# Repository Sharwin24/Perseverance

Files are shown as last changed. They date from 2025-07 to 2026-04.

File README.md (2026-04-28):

# Perseverance
Mobile Robot resembling NASA's Mars Perseverance Rover. Everything from scratch and open-source including mechanical design, electronics, and software. The end goal of this project is to gain experience with mobile robotics concepts including SLAM, state estimation, and dynamic environment navigation.

## Work In Progress


This project is currently in progress and I'm currently focusing on the drive-base with the following tasks:

- Building a Kalman Filter focusing on the kinematic model of a 6-wheel Mars Rover
- ~~Creating a PPO RL training pipeline for a simplified mobile robot and goal pose navigation~~
- Working on firmware for motor board (RoverFirmware)
- Designing a carrier PCB to connect the MCU with motors, sensors, and power.

---

<div style="display: flex; justify-content: center; align-items: flex-start; gap: 12px;">
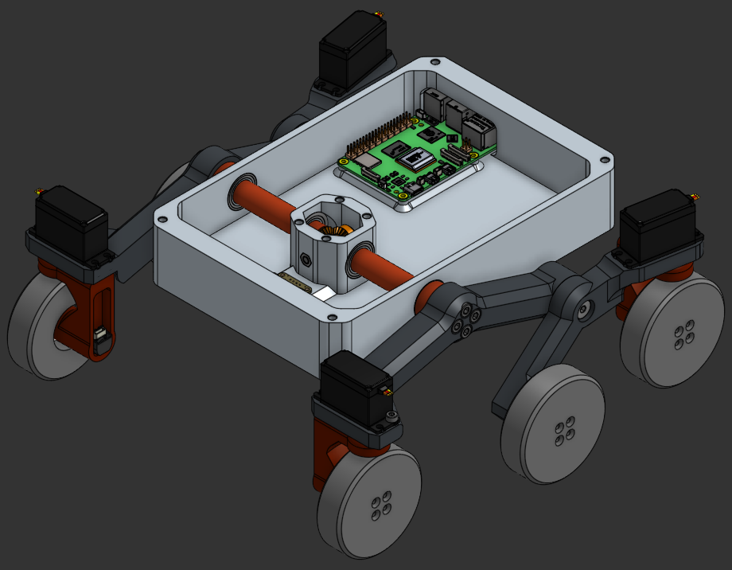
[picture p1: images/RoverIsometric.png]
Isometric CAD View
  
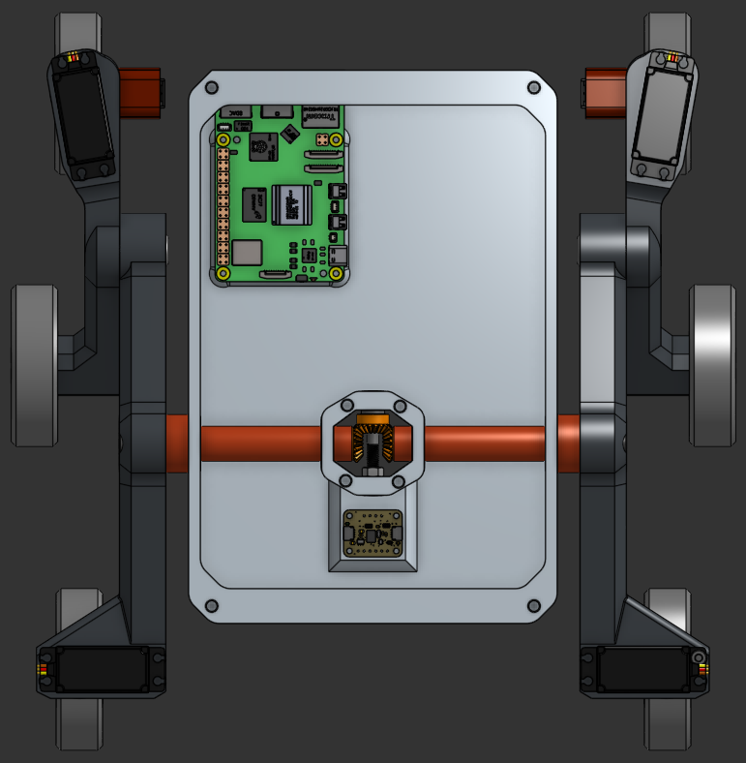
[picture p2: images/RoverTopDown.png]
Top Down CAD View
  
</div>

<div style="display: flex; justify-content: center; align-items: center; width: 80%;">
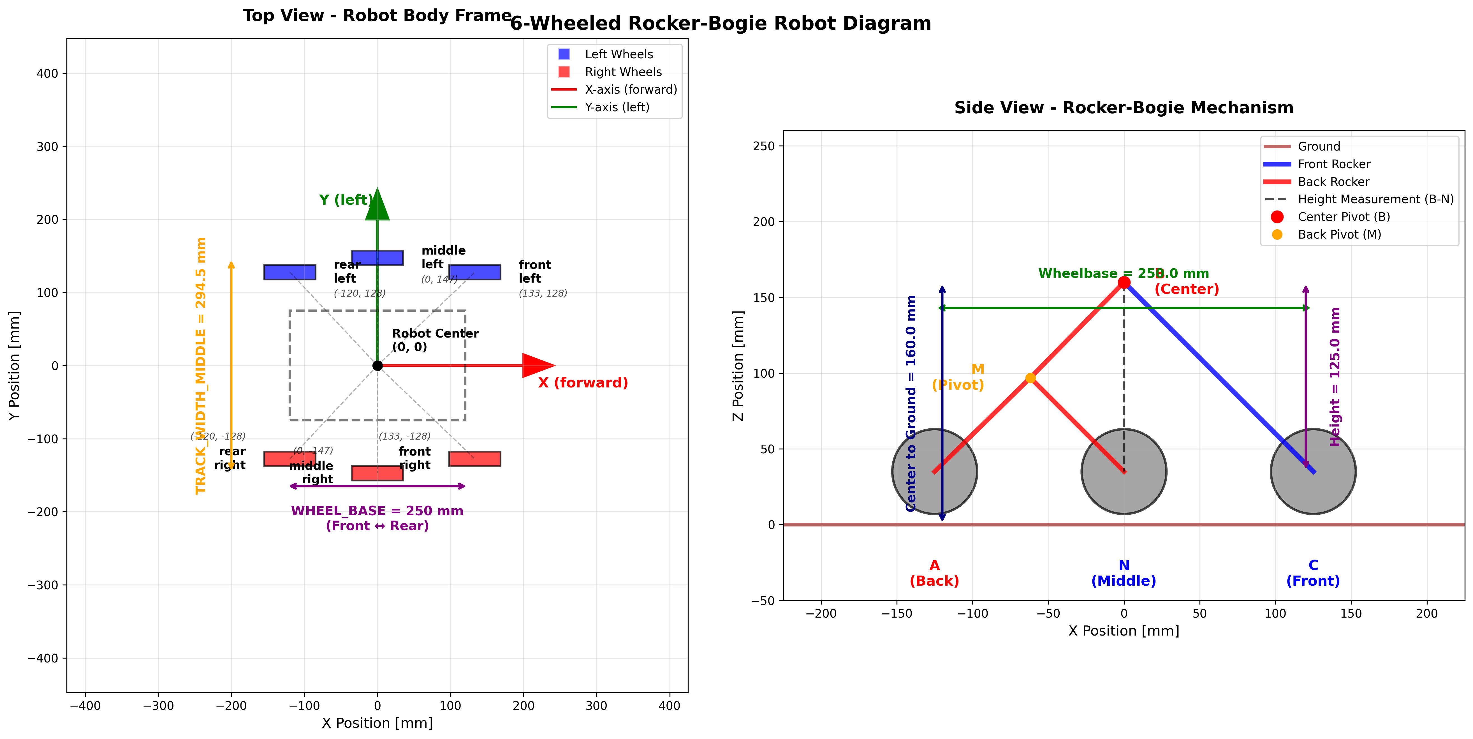
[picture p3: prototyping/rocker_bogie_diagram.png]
  
</div>

*This plot was generated with `draw_rocker_bogie.py`*

*A lot of the math expressions aren't rendering correctly and can best be visualized by viewing the markdown render locally in an IDE (VS Code). It's a work in progress to create SVG images for each equation and display them once they are finalized...*

<div style="display: flex; justify-content: center; align-items: center; width: 50%;">
  RoverTeleop
</div>

*Simulated Teleoperation in pygame with ackerman steering, try it out by running `rover_teleop.py` in `prototyping/`!*

---

# References
- [Path Following using Visual Odometry for a Mars Rover
in High-Slip Environments](https://www-robotics.jpl.nasa.gov/media/documents/helmick04_aeroconf.pdf)
- [Feature-Based Scanning LiDAR-Inertial Odometry Using Factor Graph Optimization](https://ieeexplore.ieee.org/abstract/document/10100875/authors#authors)
- [Autonomous robotics is driving Perseverance rover’s progress on Mars](https://www.science.org/doi/10.1126/scirobotics.adi3099)
- [A Friction-Based Kinematic Model for
Skid-Steer Wheeled Mobile Robots](https://amrl.cs.utexas.edu/papers/icra2019_skid_steer_kinematics.pdf)
- [Kalman Filter Overview](https://www.kalmanfilter.net/default.aspx)
- [Ghost IV — Sensor Fusion: Encoders + IMU](https://medium.com/hackernoon/ghost-iv-sensor-fusion-encoders-imu-c099dd40a7b)
- [Design of Rocker-Bogie Mechanism](https://ijisrt.com/wp-content/uploads/2017/05/Design-of-Rocker-Bogie-Mechanism-1.pdf)
- [The Challenges of Designing the Rocker-Bogie Suspension
for the Mars Exploration Rover](https://esmats.eu/amspapers/pastpapers/pdfs/2004/harrington.pdf)
- [Design and Fabrication of six wheels Rocker Bogie Mechanisms](https://sist.sathyabama.ac.in/sist_naac/aqar_2022_2023/documents/1.3.4/mechatronics_batch%20no.21.pdf)
- [Understanding and Making Rocker-Bogie System](https://docs.sunfounder.com/projects/galaxy-rvr/en/latest/lesson2_rocker_bogie.html
)

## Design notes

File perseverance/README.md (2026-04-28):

# Perseverance (ROS2 Package)
Package for navigation and control of an autonomous Mars rover using ROS2. Modeled after NASA's Perseverance rover.

# Extended Kalman Filter for Rover State Estimation
Approximating the robot as a diff-drive robot makes it easier to compute the state transition matrix and derive the system dynamics/kinematics. Kinematic models for mecanum wheeled drive and rocker bogie suspension system are more complex, but better represent the robot's motion, and I've implemented motion models for all 3.

*Note: Each motion model still needs to be tested rigorously*

<div style="display: flex; justify-content: space-between; align-items: flex-start; gap: 8px;">
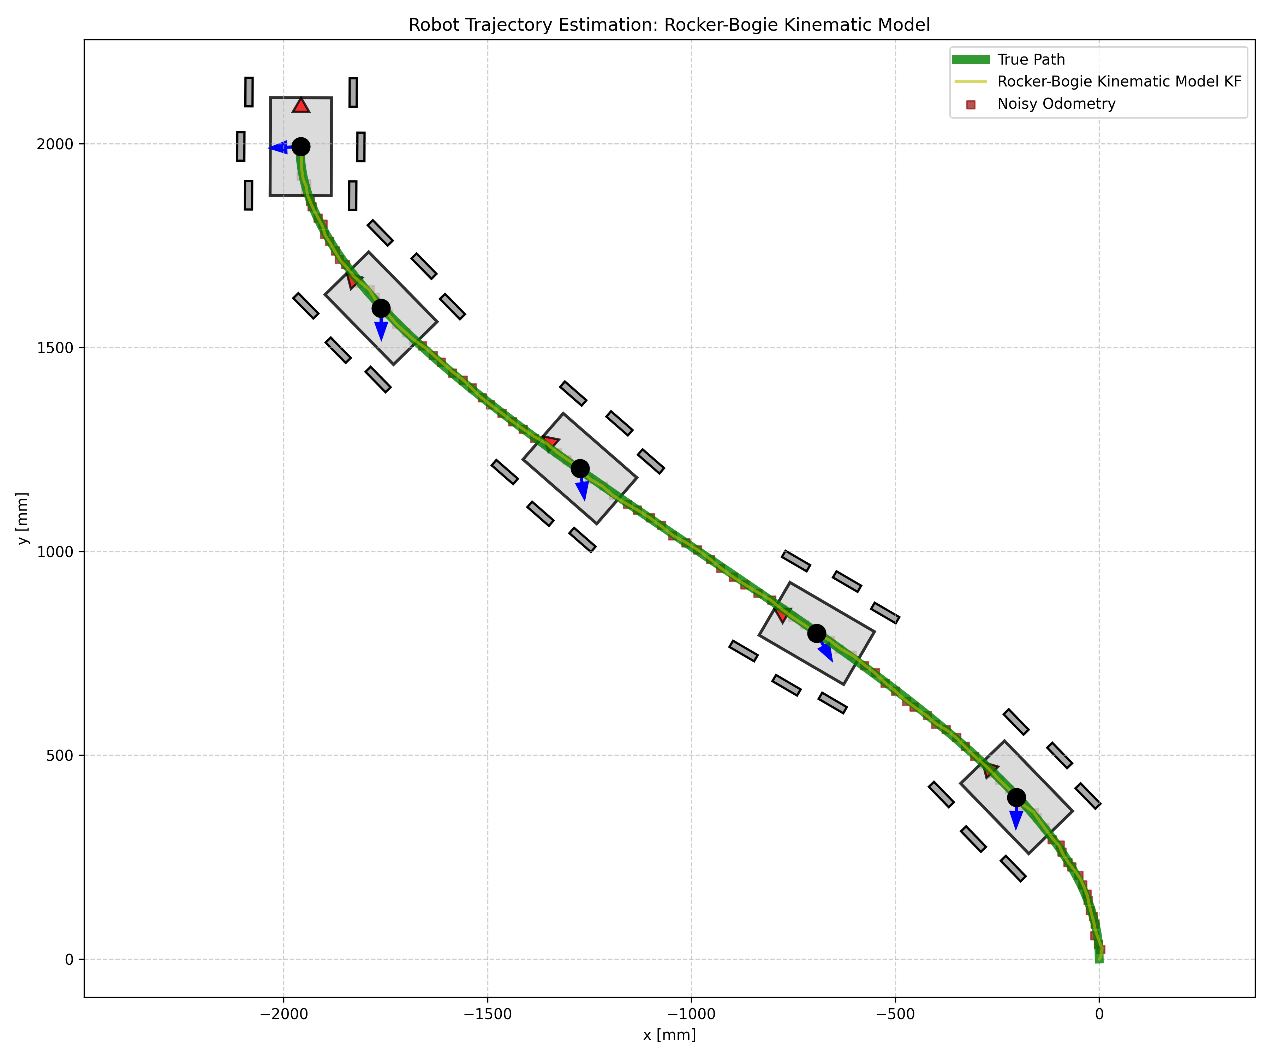
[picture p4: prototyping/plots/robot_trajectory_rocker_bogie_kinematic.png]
Robot Trajectory Comparison
  
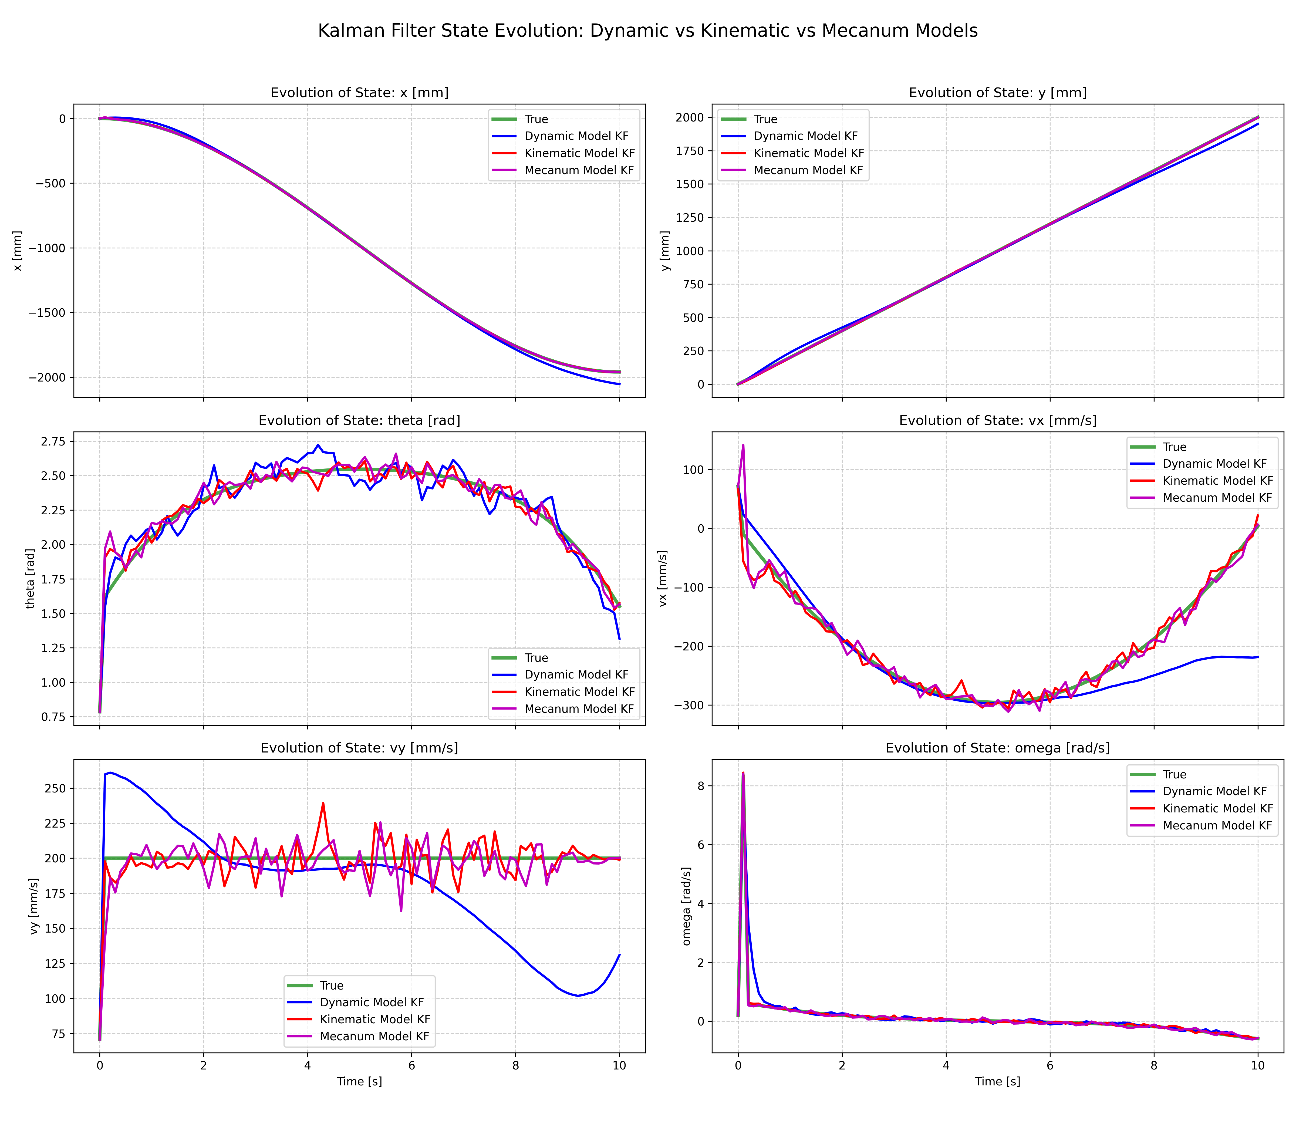
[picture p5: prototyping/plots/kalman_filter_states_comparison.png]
Kalman Filter States Comparison
  
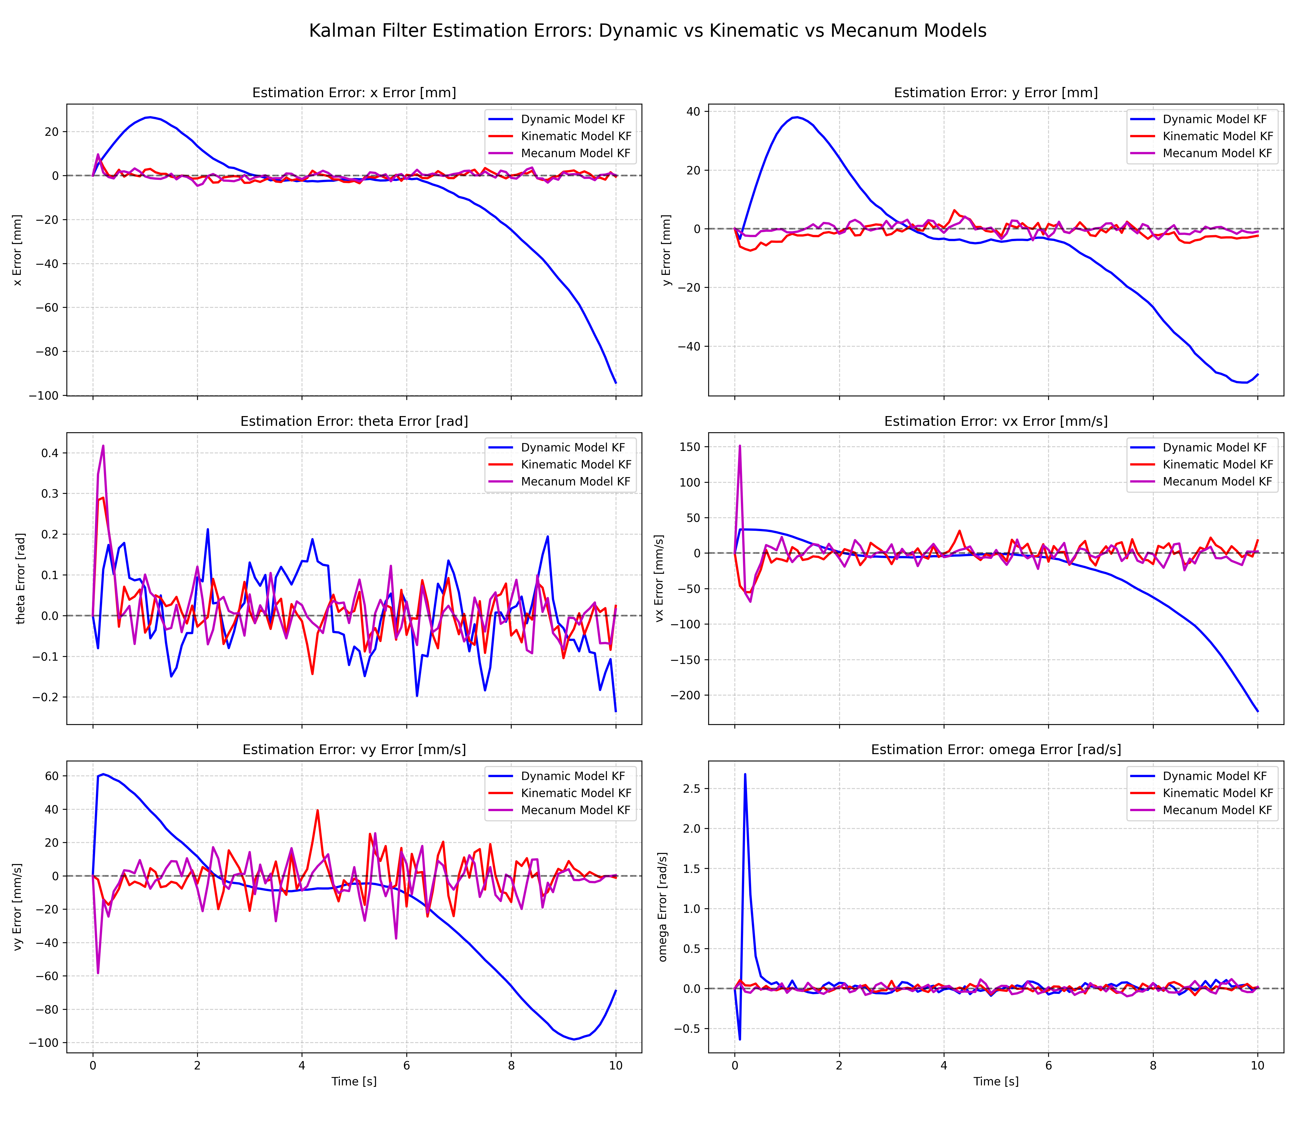
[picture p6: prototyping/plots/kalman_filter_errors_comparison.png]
Kalman Filter Errors Comparison
  
</div>

## Prediction Models

### Diff-drive Kinematic Model
The control input for the diff-drive robot is very simply both wheel velocities:

$$U_{\text{diff}} = \left[v_{left}, v_{right}\right]$$

The function that describes the state's evolution is the **process model:** $f\left(X_{prev}, U, \Delta t\right) \to X_{next}$ which correlates a previous state to the next state with some timestep $\Delta t$.

<!-- $$\begin{bmatrix}x \\ y \\ \theta \\ v_{x} \\ v_{y} \\ \omega \end{bmatrix} = \begin{bmatrix}x_{prev} + V \cos\theta_{prev} \Delta t \\ y_{prev} + V\sin\theta _{prev}\Delta t \\ \theta_{prev} + \omega \Delta t \\ V a_x \Delta t \\ V a_y \Delta t \\ \omega\end{bmatrix}$$ -->

<div style="display: flex; justify-content: center; align-items: center; width: 100%; background: black; padding: 10px; border-radius: 8px;">
  Process Model Equation
</div>

The state transition matrix $F$ (also known as the Jacobian of the process model) describes how a new state relates to the old state as a matrix of partial derivatives.

<!-- $$F = \begin{bmatrix} 1 & 0 & -V\sin(\theta)\Delta t & 0 & 0 & 0 \\ 0 & 1 & V\cos(\theta)\Delta t & 0 & 0 & 0 \\ 0 & 0 & 1 & 0 & 0 & 0 \\ 0 & 0 & -V\sin(\theta_{new}) & 0 & 0 & 0 \\ 0 & 0 & V\cos(\theta_{new}) & 0 & 0 & 0 \\ 0 & 0 & 0 & 0 & 0 & 0 \end{bmatrix}$$ -->

<div style="display: flex; justify-content: center; align-items: center; width: 100%; background: black; padding: 10px; border-radius: 8px;">
  F_diff_drive_kinematic Matrix
</div>

### Rocker-Bogie Suspension Kinematic Model
The rocker-bogie suspension has 6 powered wheels, 4 of which are able to rotate independently for ackerman-style steering. The control vector includes all wheel velocities and the 4 (outer) wheel steering angles:

$$U_{\text{rocker-bogie}} = \left[v_1, v_2, v_3, v_4, v_5, v_6, \theta_1, \theta_2, \theta_3, \theta_4\right]$$

Each wheel $i$ at position $(x_i,y_i)$ (in the body frame) with steering angle $\delta_i$ and drive speed $v_i$ provides two constraints on body-frame velocities $(v_{bx}, v_{by}, \omega_b)$:

$$\begin{aligned}
v_{bx} - \omega_b y_i &= v_i \cos\delta_i \\
v_{by} + \omega_b x_i &= v_i \sin\delta_i
\end{aligned}$$

Stacking all 6 wheels yields a linear system $A\,\mathbf{b} = \mathbf{m}$ with $A \in \mathbb{R}^{12\times 3}$, unknown $\mathbf{b} = [v_{bx}, v_{by}, \omega_b]^T$, and measurement vector $\mathbf{m}$ composed of $v_i\cos\delta_i, v_i\sin\delta_i$ pairs. The least-squares solution:

$$\begin{bmatrix} v_{bx} \\ v_{by} \\ \omega_b \end{bmatrix} = (A^{T}A)^{-1}A^{T} \mathbf{m} = A^{\dagger}\,\mathbf{m}$$

Body velocities are transformed to global frame and integrated:

$$\begin{aligned}
\dot{x} &= v_{bx}\cos\theta - v_{by}\sin\theta\\
\dot{y} &= v_{bx}\sin\theta + v_{by}\cos\theta\\
\dot{\theta} &= \omega_b
\end{aligned}$$

Discrete process model with state $X = [x, y, \theta, v_x, v_y, \omega]^T$ (using global-frame velocities $v_x, v_y$):

$$\begin{bmatrix} x_{k+1} \\ y_{k+1} \\ \theta_{k+1} \\ v_{x,k+1} \\ v_{y,k+1} \\ \omega_{k+1} \end{bmatrix} = \begin{bmatrix}
 x_k + v_{x,k}\Delta t \\
 y_k + v_{y,k}\Delta t \\
 \theta_k + \omega_k \Delta t \\
 v_{x}^{(b)\to g}(U_k) \\
 v_{y}^{(b)\to g}(U_k) \\
 \omega_b(U_k)
\end{bmatrix}$$

Because $v_x, v_y, \omega$ are fully determined by wheel inputs each step, their derivatives w.r.t prior velocities are zero in the Jacobian (similar sparsity to mecanum). Non-linear dependence enters only through the heading rotation applied to $(v_{bx}, v_{by})$.

<!-- $$
F = \frac{\delta f(X,U)}{\delta X} =\begin{bmatrix}\frac{\delta x_{new}}{\delta x} & \frac{\delta x_{new}}{\delta y} & \frac{\delta x_{new}}{\delta \theta} & \frac{\delta x_{new}}{\delta v_x} & \frac{\delta x_{new}}{\delta v_y}\\ \frac{\delta y_{new}}{\delta x} & \frac{\delta y_{new}}{\delta y} & \frac{\delta y_{new}}{\delta \theta} & \frac{\delta y_{new}}{\delta v_x} & \frac{\delta y_{new}}{\delta v_y}\\ \frac{\delta \theta_{new}}{\delta x} & \frac{\delta \theta_{new}}{\delta y} & \frac{\delta \theta_{new}}{\delta \theta} & \frac{\delta \theta_{new}}{\delta v_x} & \frac{\delta \theta_{new}}{\delta v_y}\\ \frac{\delta v_{x_{new}}}{\delta x} & \frac{\delta v_{x_{new}}}{\delta y} & \frac{\delta v_{x_{new}}}{\delta \theta} & \frac{v_{x_{new}}}{\delta v_x} & \frac{v_{y_{new}}}{\delta v_y} \\ \frac{\delta v_{y_{new}}}{\delta x} & \frac{\delta v_{y_{new}}}{\delta y} & \frac{\delta v_{y_{new}}}{\delta \theta} & \frac{v_{y_{new}}}{\delta v_x} & \frac{v_{y_{new}}}{\delta v_y}\end{bmatrix} = \begin{bmatrix} 1 & 0 & -V\sin(\theta)\Delta t & 0 & 0 & 0 \\ 0 & 1 & V\cos(\theta)\Delta t & 0 & 0 & 0 \\ 0 & 0 & 1 & 0 & 0 & 0 \\ 0 & 0 & -V\sin(\theta_{new}) & 0 & 0 & 0 \\ 0 & 0 & V\cos(\theta_{new}) & 0 & 0 & 0 \\ 0 & 0 & 0 & 0 & 0 & 0 \end{bmatrix}
$$ -->

<div style="display: flex; justify-content: center; align-items: center; width: 100%; background: black; padding: 10px; border-radius: 8px;">
  State Transition Matrix
</div>

Note that the new velocities and angular rate do not depend on the previous velocities or angular rate, making their corresponding derivatives zero. The new velocities, $(v_x, v_y)$ are determined by the control input $V$ and the *new* orientation $\theta_{new}$. This is a *non-linear* process model because of the use of trigonometric functions on the state variable $\theta$.

### Mobile Robot Dynamic (Acceleration-Based) Model
This model treats measured linear accelerations (e.g., IMU) as control inputs producing a constant-acceleration (CA) motion assumption over each small interval $\Delta t$.

State (extended to include velocities & yaw rate):
$$X = [x, y, \theta, v_x, v_y, \omega]^T$$

Control Vector (global-frame linear accelerations):
$$U_{\text{imu}} = [a_x, a_y]^T$$

Continuous dynamics (assuming measured $\omega$ is incorporated separately via a gyro measurement update):
$$\begin{aligned}
\dot{x} &= v_x & \dot{v}_x &= a_x \\
\dot{y} &= v_y & \dot{v}_y &= a_y \\
\dot{\theta} &= \omega & \dot{\omega} &= 0
\end{aligned}$$

Discretized (first-order) process model:
$$\begin{bmatrix} x_{k+1} \\ y_{k+1} \\ \theta_{k+1} \\ v_{x,k+1} \\ v_{y,k+1} \\ \omega_{k+1} \end{bmatrix} = \begin{bmatrix}
 x_k + v_{x,k}\Delta t + \tfrac{1}{2} a_{x,k}\Delta t^2 \\
 y_k + v_{y,k}\Delta t + \tfrac{1}{2} a_{y,k}\Delta t^2 \\
  heta_k + \omega_k \Delta t \\
 v_{x,k} + a_{x,k}\Delta t \\
 v_{y,k} + a_{y,k}\Delta t \\
 \omega_k
\end{bmatrix}$$

This can be written in linear form $X_{k+1} = F X_k + B U_k$ where:

$$F = \begin{bmatrix}
1 & 0 & 0 & \Delta t & 0 & 0 \\
0 & 1 & 0 & 0 & \Delta t & 0 \\
0 & 0 & 1 & 0 & 0 & \Delta t \\
0 & 0 & 0 & 1 & 0 & 0 \\
0 & 0 & 0 & 0 & 1 & 0 \\
0 & 0 & 0 & 0 & 0 & 1
\end{bmatrix}, \quad
B = \begin{bmatrix}
  \frac{1}{2}\Delta t^2 & 0 \\
0 & \frac{1}{2}\Delta t^2 \\
0 & 0 \\
\Delta t & 0 \\
0 & \Delta t \\
0 & 0
\end{bmatrix}$$

Yaw rate $\omega$ is modeled as constant between corrections (process noise captures drift). If desired, a third acceleration/torque input could be added to extend $B$ for angular acceleration.

## Robot State & Covariance
The goal of the prediction step in a Kalman filter is to use the prediction model to calculate how the robot's state evolves over a time step $\Delta t$. This model is based on control inputs, which are the commands we send to the robot. Any given state may have some error, and it's important to capture this uncertainty in our state representation with what we call a state covariance matrix, typically denoted as $P$. The state covariance matrix describes the uncertainty of each state variable and how they are correlated with each other, and is usually a diagonal matrix, unless there are state variables that are correlated with each other.

$$X = \left[x, y, \theta, v_x, v_y, \omega\right]$$

$$P = \begin{bmatrix}
\sigma_x^2 & 0 & 0 & 0 & 0 & 0 \\
0 & \sigma_y^2 & 0 & 0 & 0 & 0 \\
0 & 0 & \sigma_\theta^2 & 0 & 0 & 0 \\
0 & 0 & 0 & \sigma_{v_x}^2 & 0 & 0 \\
0 & 0 & 0 & 0 & \sigma_{v_y}^2 & 0 \\
0 & 0 & 0 & 0 & 0 & \sigma_\omega^2
\end{bmatrix}$$

### Tuning the Initial State Covariance $(P)$
The initial state covariance $P$ should be the variance of the initial state values. Typically the initial state is all zeros and the covariances can be small.

### Tuning the Process Noise Covariance $(Q)$
$Q$ represents how much confidence we have in our prediction model. Typically kinematic models are pretty robust, for diff-drive robots at least, but can accumulate some inaccuracy for skid-steering and mecanum wheeled drive bases. Smaller values trust the prediction model more, while larger values alot more trust to the sensor measurements that are used to correct the robot's state. This should be tuned last after tuning the initial covariance $P$, and the measurement covariances $R$ (discussed below).

### Updating Covariance Matrices
During each **prediction step**, we learn more about the system's dynamics and need to update our state-covariance matrix to reflect this new knowledge:

$$ P_{k+1} = F P_k F^T + Q $$

During the **update step**, we also need to update the state covariance matrix to reflect the new information gained from the sensor measurements. We do this with the kalman gain $K$, the innovation covariance $S$ and the measurement noise covariance $R$:

$$S = H P_{k} H^T + R$$

$$K = P_{k} H^T S^{-1}$$

$$P_{k+1} = (I - K H) P_{k}$$

## Sensor Fusion Updates
The correction step of the filter uses sensor measurements to refine the predicted state. For each sensor, we need a measurement model $H(X)$ that computes the expected measurement from a given state vector.

### IMU Sensor
The IMU measures the angular rate around the Z-axis $\omega$ as well as the linear acceleration $a_x, a_y$.

$$z_{imu} = \left[\omega, a_x, a_y\right]$$

The measurement model only needs to use the angular velocity

$$H_{imu}(X) = \left[0, 0, 0, 0, 0, 1\right]$$

### Odometry
Odometry uses wheel encoders coupled with knowledge about the robot's physical layout to obtain an estimate of the robot's pose:

$$z_{odom} = \left[x_{odom}, y_{odom}, \theta_{odom}\right]$$

The measurement model selects the pose elements from the state:

$$H_{odom}(X) = \left[1, 1, 1, 0, 0, 0\right]$$

### Tuning Measurement Noise Covariance $(R)$
Collect data with the robot sitting absolutely still for a specified length of time and calculate the variance of the data set for each sensor's respective values in the measurement model.

$$R \approx \sigma^2 = \frac{1}{N}\sum_i^N\left(x_i - \mu\right)^2$$

The datasheet for each sensor could prove to be useful if they've documented the sensor's noise density and/or standard deviation.

## State Estimation Pipeline
Now that we're equipped with jargon and the individual components of the EKF, we can outline the state estimation pipeline with some pseudocode:

```python
# 1. Initialize state and covariance
X = np.zeros((6, 1)) # [x, y, theta, v_x, v_y, omega]
P = np.eye(6) * 1e-3 # State Covariance Matrix
Q = np.eye(6) * 1e-3 # Process Noise Covariance Matrix
prev_estimate_time = 0 # Timestamp for the previous update

# Loop through prediction and update step
# This typically happens at a fixed time interval e.g. every 100ms or 10Hz
while True:
  # Calculate timestep between estimations
  current_time = now()
  dt = current_time - prev_estimate_time
  if (dt <= 0):
    continue;

  # 2. Prediction Step
  # 2.1 Predict the next state using the process model
  X_new = process_model(X, dt)

  # 2.2 Calculate the Jacobian F
  F = calculate_jacobian(X, dt)

  # 2.3. Update the state covariance
  P = F @ P @ F.T + Q

  # 3. Update Step
  for [z, H, R] in sensor_readings:
    # z is the measurement vector from the sensor
    # H is the measurement model matrix for the sensor
    # R is the measurement noise covariance for this sensor

    # 3.1 Calculate the innovation
    y = z - H @ X_new

    # 3.2 Calculate the innovation covariance [S]
    S = H @ P @ H.T + R

    # 3.3 Calculate the kalman gain [K]
    K = P @ H.T @ np.linalg.inv(S)

    # 3.4 Update the state estimate
    X = X_new + K @ y

    # 3.5 Update the state covariance
    P = (np.eye(6) - K @ H) @ P

  # Update estimate timestamp before next loop execution
  prev_estimate_timestamp = current_time
```

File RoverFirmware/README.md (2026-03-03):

# RoverFirmware
Firmware for the [**Adafruit Feather M4 Express**](https://www.adafruit.com/product/3857) (SAMD51, Cortex-M4F) on the rover, handling low-level motor control and SPI communication with the Raspberry Pi 5.

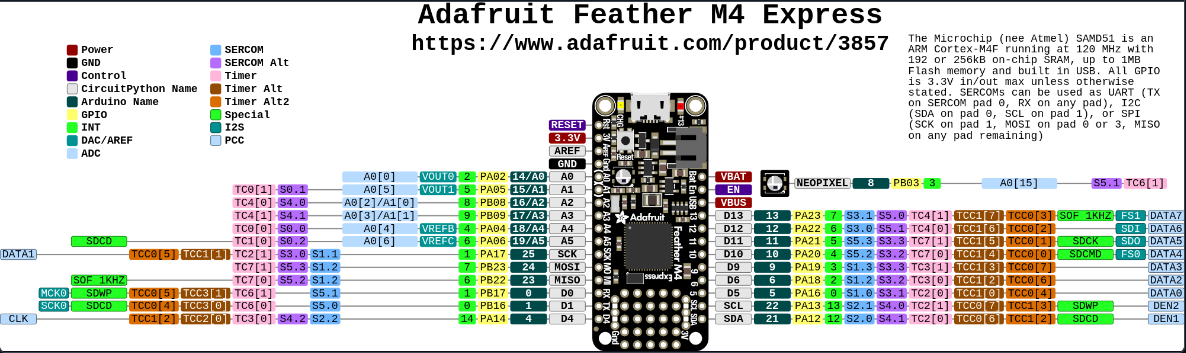
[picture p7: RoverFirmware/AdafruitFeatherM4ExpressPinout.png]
Adafruit Feather M4 Express Pinout


## Why the Feather M4 Express?

The M4 Express was chosen over alternatives (RP2040, Teensy 4.1) for the following reasons:

- **Hardware FPU:** The SAMD51 has a single-precision hardware FPU, making the PID loops across 6 motors at 100Hz fast and deterministic. The RP2040 has no hardware FPU, so all floating-point math runs in software emulation.
- **Interrupt-capable GPIOs:** Every digital pin supports external interrupts, covering all 12 pins needed for 6 quadrature encoders without workarounds.
- **Adafruit library compatibility:** First-class support for `Adafruit_MotorShield`, `Adafruit_BusIO`, and `Adafruit_MAX1704X`. The RP2040's community Arduino core has occasional compatibility quirks with these libraries.
- **PlatformIO support:** The M4 has native PlatformIO support. The RP2040 requires the community `maxgerhardt/platform-raspberrypi` platform and needed workarounds (e.g., `-DENCODER_DO_NOT_USE_INTERRUPTS`) that would defeat high-frequency encoder reading.

## Hardware Interfaces

1. Control 6 DC drive motors via 2× Adafruit Motor Shield FeatherWings (I2C)
2. Control 4 steering servos (PWM)
3. Read from 6 quadrature encoders (12 interrupt pins)
4. Communicate with Raspberry Pi 5 over SPI

## SPI Protocol

**RPi5 → M4:**
- 6 motor target speeds
- 4 servo steering angles

**M4 → RPi5:**
- 6 encoder counts (for wheel odometry)

## Concurrent Tasks

All tasks run cooperatively using `ArduinoThread`, checked in priority order in `loop()`:

| Priority | Task | Rate | Description |
|---|---|---|---|
| 1 | Encoder Task | 1 kHz | Reads 6 quadrature encoders and updates encoder counts |
| 2 | Motor Task | 100 Hz | PID velocity control for 6 DC motors, updates FeatherWing PWM |
| 3 | Steering Task | 100 Hz | Updates 4 steering servos based on RPi5 commands |
| 4 | Communication Task | 100 Hz | SPI — receives commands from RPi5, sends back encoder data |
| 5 | Battery Monitor Task | 0.5 Hz | Polls MAX17048 alerts and controls charging circuit |
| 6 | Heartbeat Task | 0.25 Hz | Pulses built-in LED to indicate scheduler is alive |

## Arduino / PlatformIO Dependencies

- [`Adafruit_MotorShield`](https://github.com/adafruit/Adafruit_Motor_Shield_V2_Library/blob/master/Adafruit_MotorShield.h)
- [`Adafruit_MS_PWMServoDriver`](https://github.com/adafruit/Adafruit_Motor_Shield_V2_Library/blob/master/utility/Adafruit_MS_PWMServoDriver.h)
- [`Adafruit_I2CDevice`](https://github.com/adafruit/Adafruit_BusIO/blob/master/Adafruit_I2CDevice.h)
- [`Adafruit_MAX1704X`](https://github.com/adafruit/Adafruit_MAX1704X) — battery fuel gauge
- [`ArduinoThread`](https://gitlab.com/airbornemint/arduino-protothreads) — cooperative multitasking

## Task Details

### Encoder Task (1 kHz)

Reads all 6 quadrature encoders using ISR-driven `Encoder` objects and stores the raw tick counts into the shared `encoderCounts[6]` array (`{FL, FR, ML, MR, RL, RR}`). Running at 1 kHz gives 1 ms resolution for the velocity estimation performed in the Motor Task.

### Motor Task (100 Hz)

Implements an independent PID velocity control loop for each of the 6 drive motors:

1. Computes `dt` in microseconds via `micros()` for precise, wrap-safe timing.
2. Derives current velocity for each motor as `(current_ticks - prev_ticks) / dt` in ticks/s.
3. Sets each PID controller's input to the measured velocity and setpoint to the commanded speed from `motorSpeedCommands[6]` (rad/s, populated by the Communication Task).
4. Maps the PID output (clamped to ±4095, 12-bit range) to `setSpeedFine()` on each `Adafruit_DCMotor`, with direction set by the sign of the output.

PID gains: `Kp = 2.0`, `Ki = 5.0`, `Kd = 1.0`. The two MotorShields sit at I2C addresses `0x60` (left side: FL, ML, RL) and `0x61` (right side: FR, MR, RR).

### Steering Task (100 Hz)

Reads the shared `servoAngleCommands[4]` array (`{FL, FR, RL, RR}` in radians) and writes positions to the 4 steering servos. Angles are converted from radians to degrees, then mapped from `[-90°, 90°]` to the `[0°, 180°]` servo range.

### Communication Task (100 Hz)

Handles the full-duplex SPI transaction with the Raspberry Pi 5:

- **TX (24 bytes):** 6 encoder counts packed as little-endian `uint32_t` values.
- **RX (40 bytes):** 6 motor speed `float`s (bytes 0–23) followed by 4 servo angle `float`s (bytes 24–39), all little-endian.

Values are unpacked via a `union { uint32_t u; float f; }` bitcast and written into `motorSpeedCommands` and `servoAngleCommands`. On a failed SPI transaction, previous command values are retained unchanged.

### Battery Monitor Task (0.5 Hz)

Polls the MAX17048 fuel gauge for active alerts and responds accordingly:

| Alert Flag | Action |
|---|---|
| `SOC_CHANGE` | Clear flag |
| `SOC_LOW` | Clear flag |
| `VOLTAGE_RESET` | Clear flag |
| `VOLTAGE_LOW` (< 3.25 V) | Assert `BATTERY_CHARGE_ENABLE_PIN` HIGH — enables charging circuit |
| `VOLTAGE_HIGH` (> 4.25 V) | Assert `BATTERY_CHARGE_ENABLE_PIN` LOW — disables charging circuit |
| `RESET_INDICATOR` | Clear flag |

Thresholds: low = 3.30 V, full = 4.20 V, hysteresis = 0.05 V (prevents rapid toggling at boundary voltages).

### Heartbeat Task (0.25 Hz)

Pulses the built-in LED for 100 ms every 4 seconds as a visual indicator that the cooperative scheduler is alive and not deadlocked.

---

## Motor Interface

`RoverMotorInterface` (RMI) wraps the two `Adafruit_MotorShield` instances and all 6 `Adafruit_DCMotor` objects. It:

1. Maintains 2 `Adafruit_MotorShield` instances (one per side of the rover)
2. Manages 6 `Adafruit_DCMotor` instances (3 per shield)
3. Exposes thread-safe setters for target velocities
4. Runs a PID control loop, reading encoder-derived velocity error and updating PWM output each Motor Task cycle

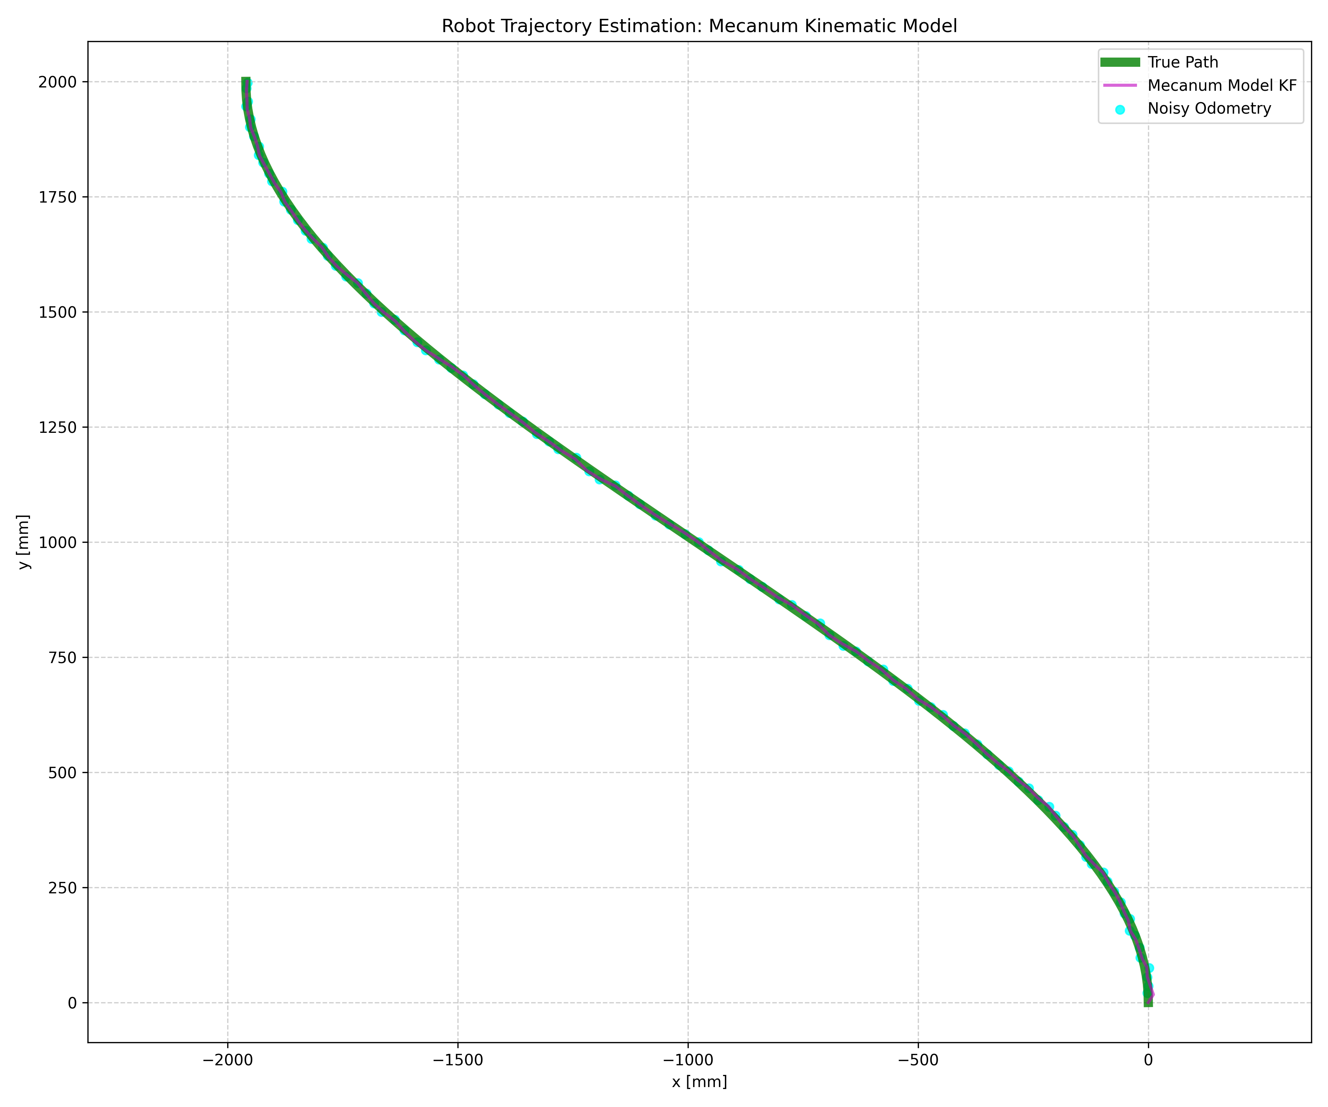
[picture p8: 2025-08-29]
prototyping/plots/robot_trajectory_mecanum_kinematic.png

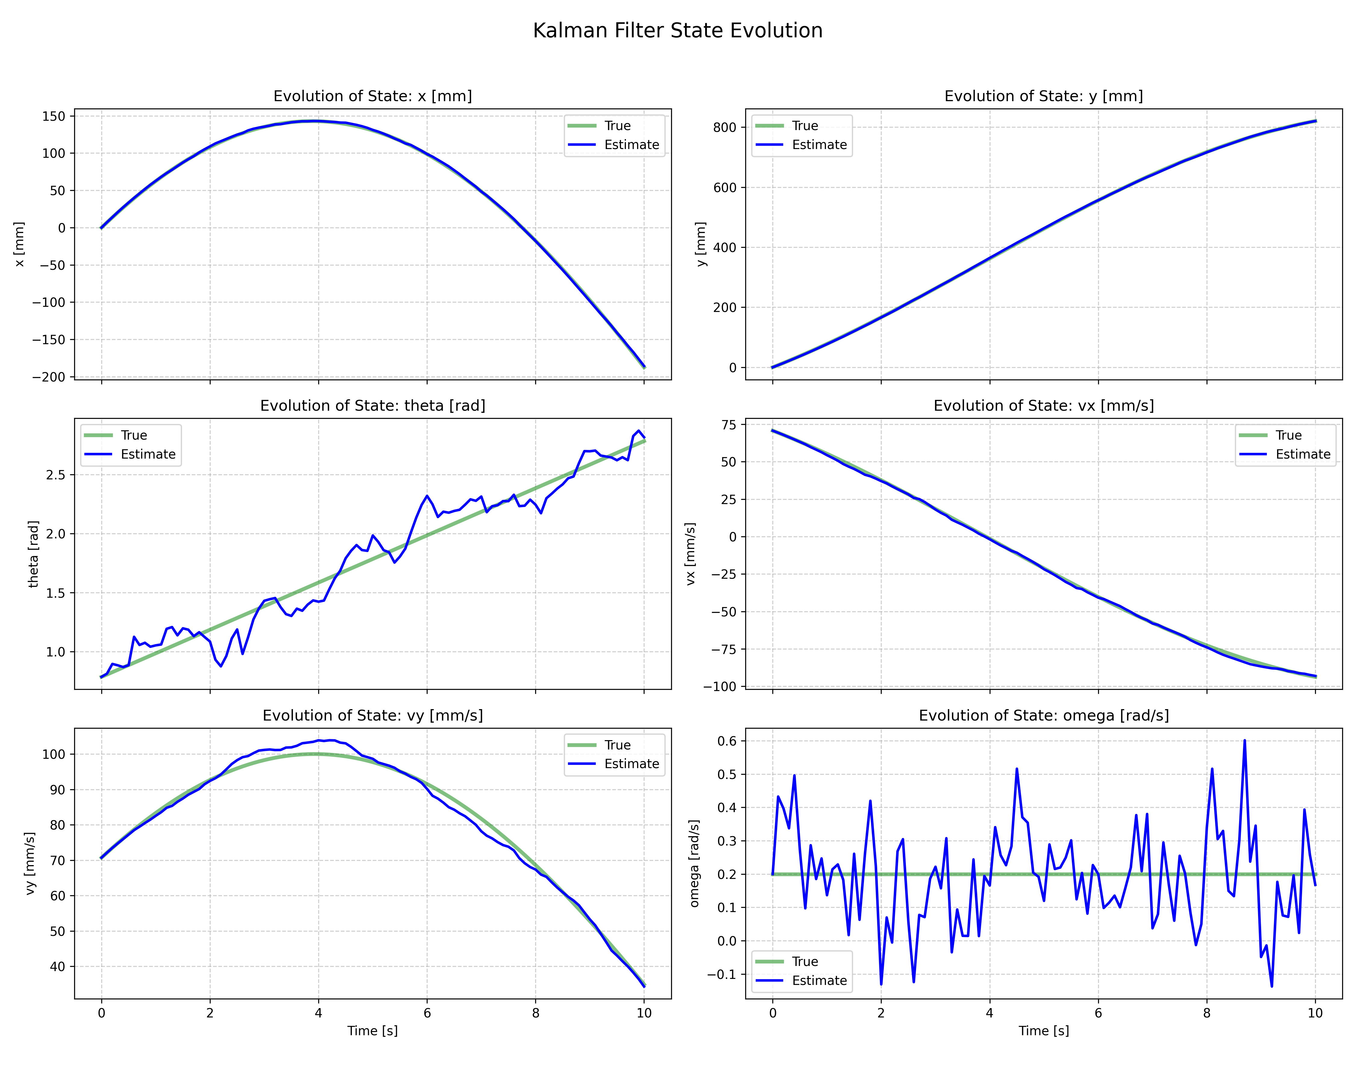
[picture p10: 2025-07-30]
prototyping/plots/gentle_curve/kalman_filter_states.png

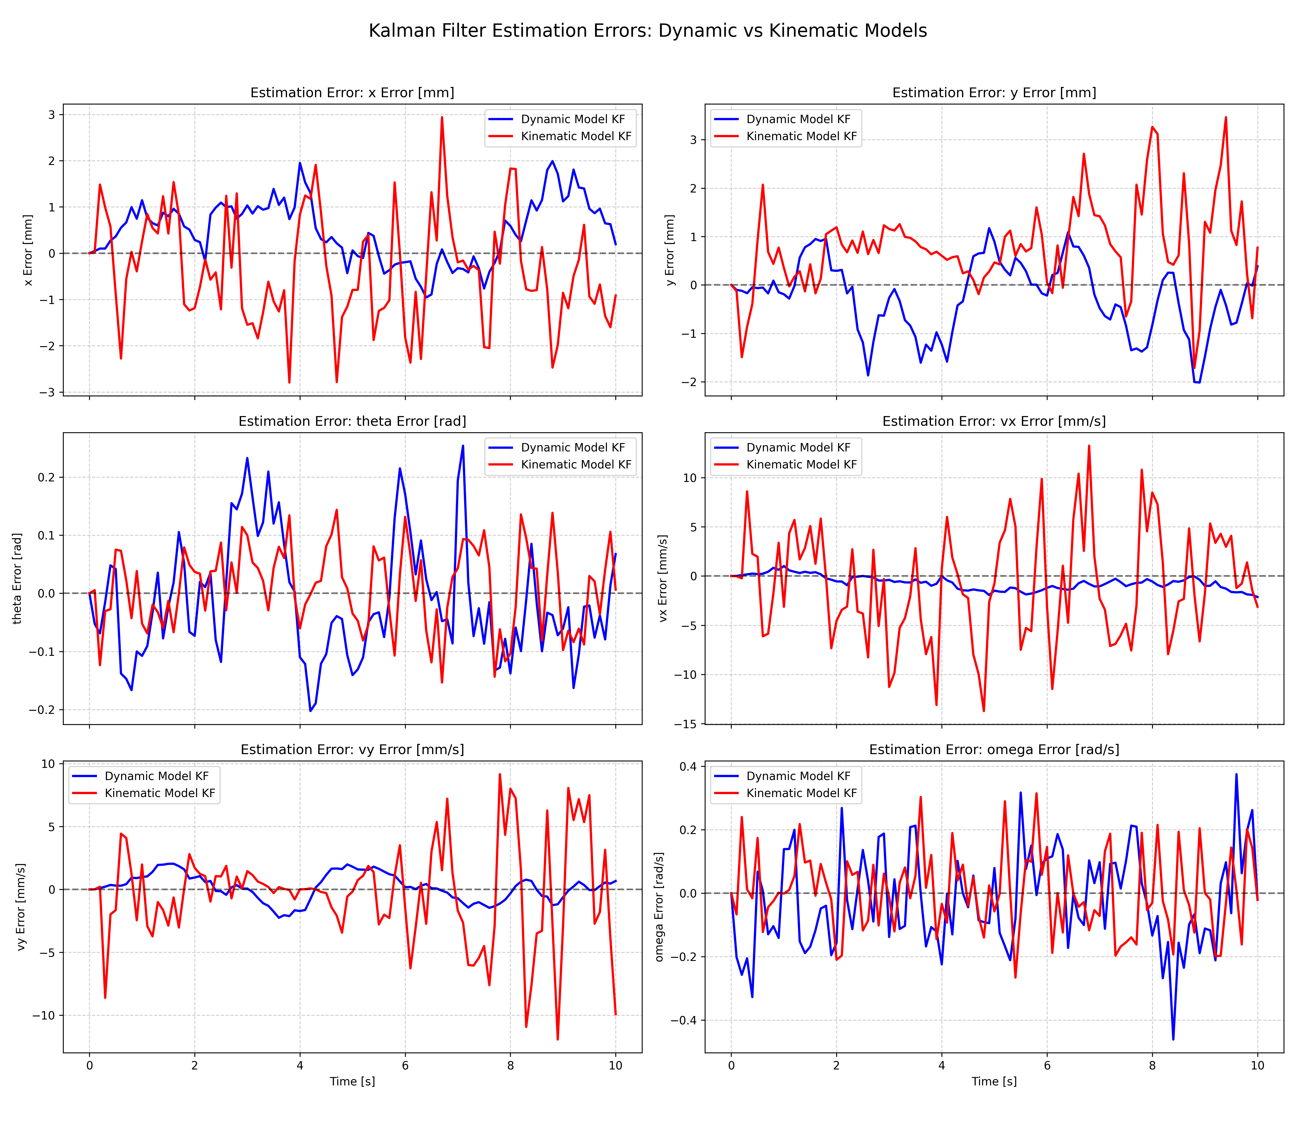
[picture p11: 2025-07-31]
prototyping/plots/gentle_curve/kalman_filter_errors_comparison.png

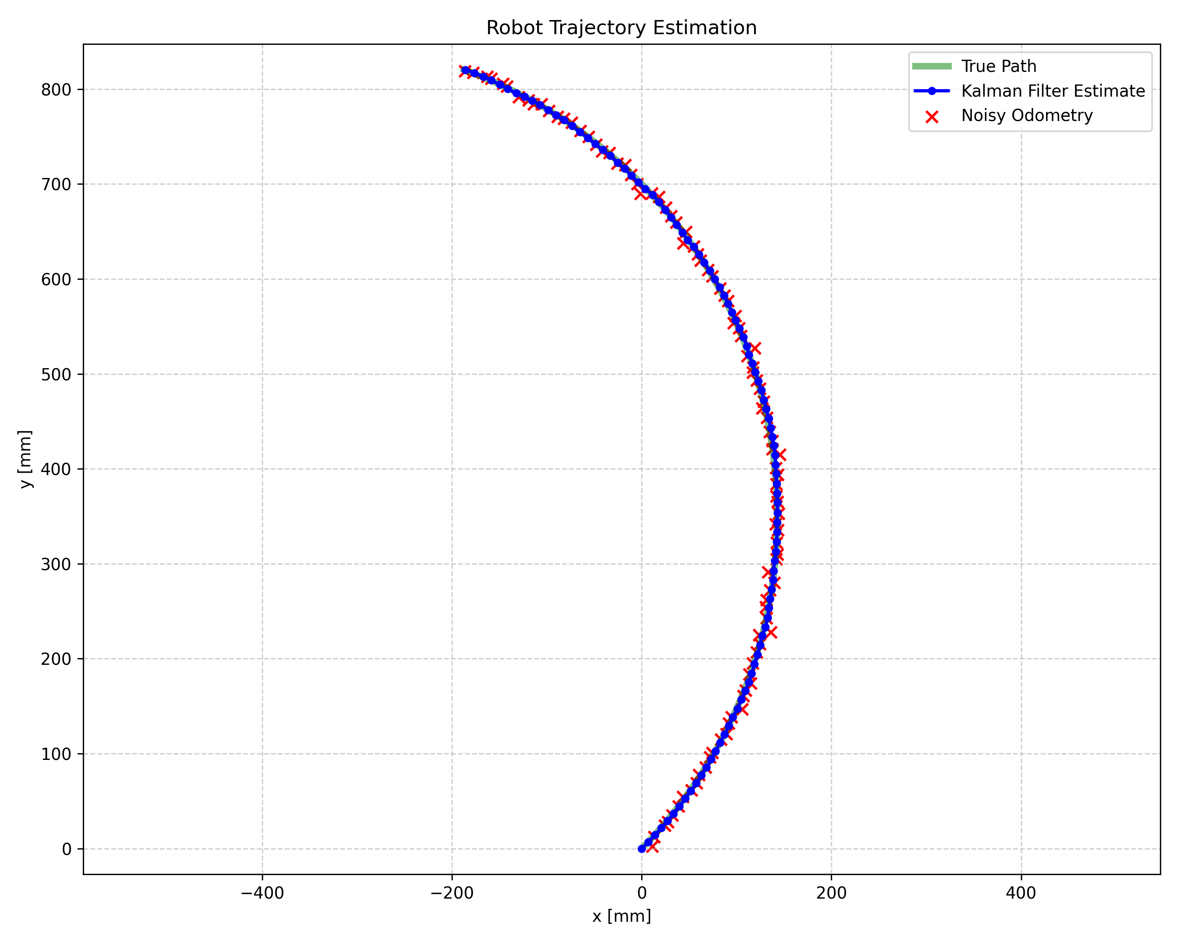
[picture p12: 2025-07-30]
prototyping/plots/gentle_curve/robot_trajectory.png

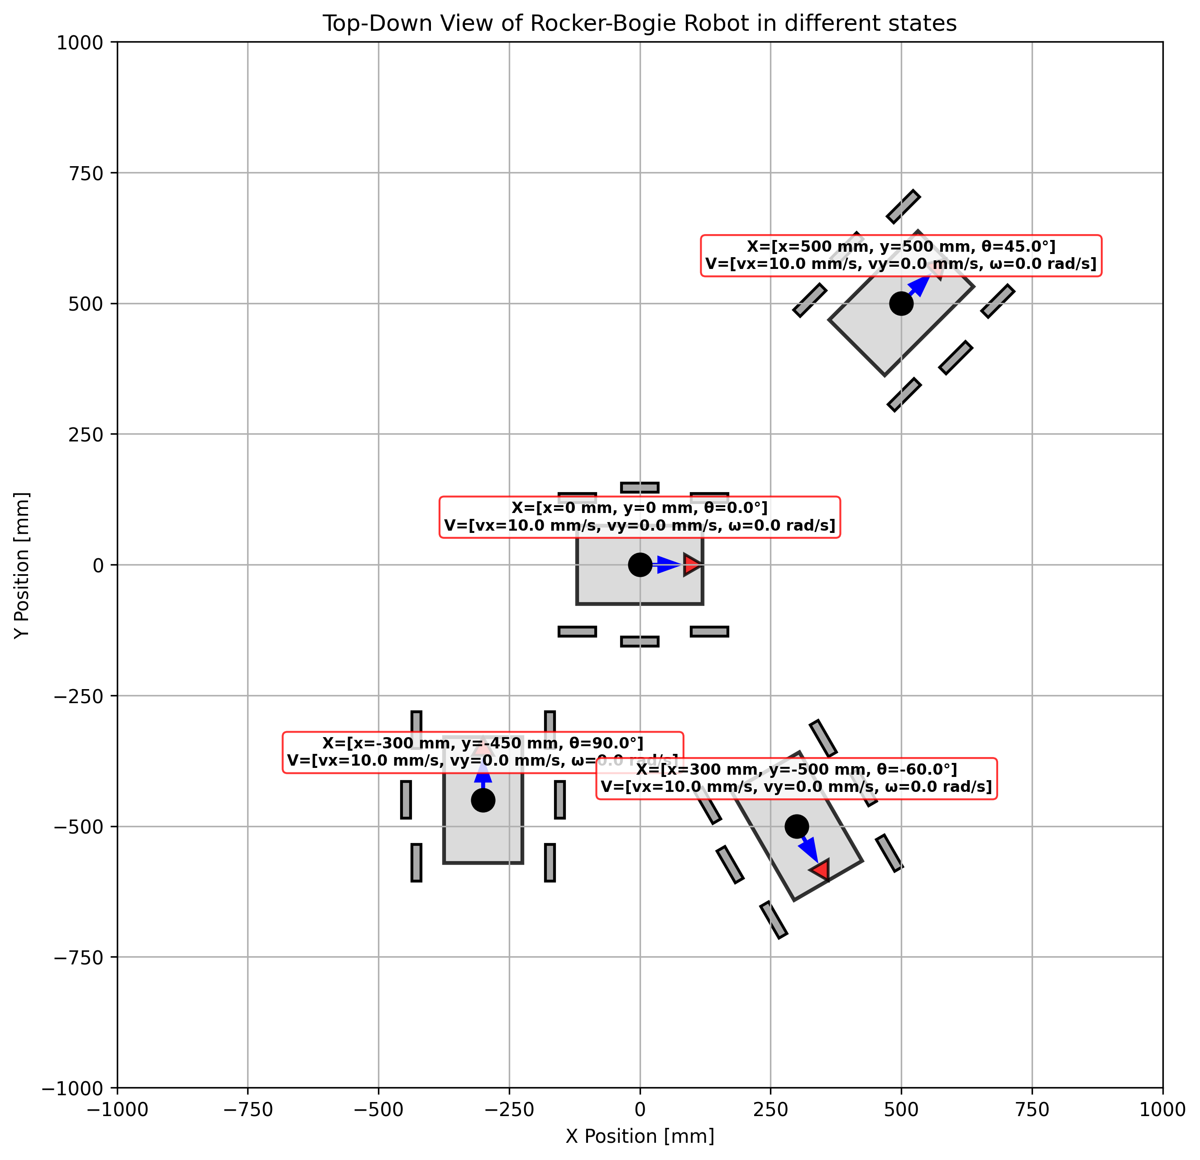
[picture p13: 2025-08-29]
prototyping/top_down_rover.png

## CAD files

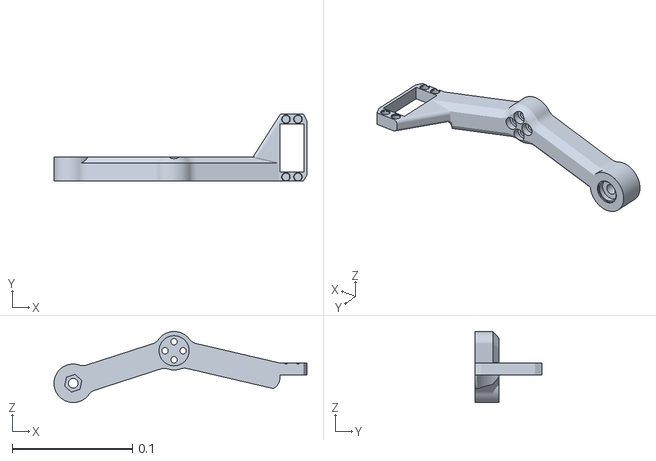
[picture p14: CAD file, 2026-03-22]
perseverance/urdf/leftrocker.stl
0.21 x 0.056 x 0.0591

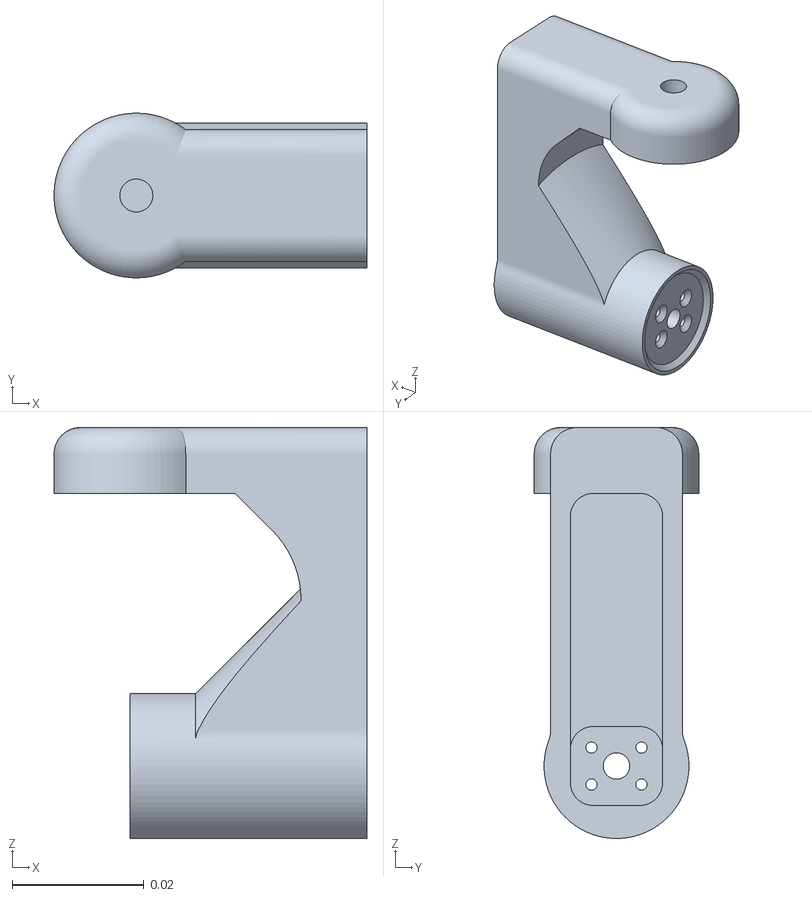
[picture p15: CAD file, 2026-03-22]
perseverance/urdf/rearsteeringarm.stl
0.0475 x 0.025 x 0.0624

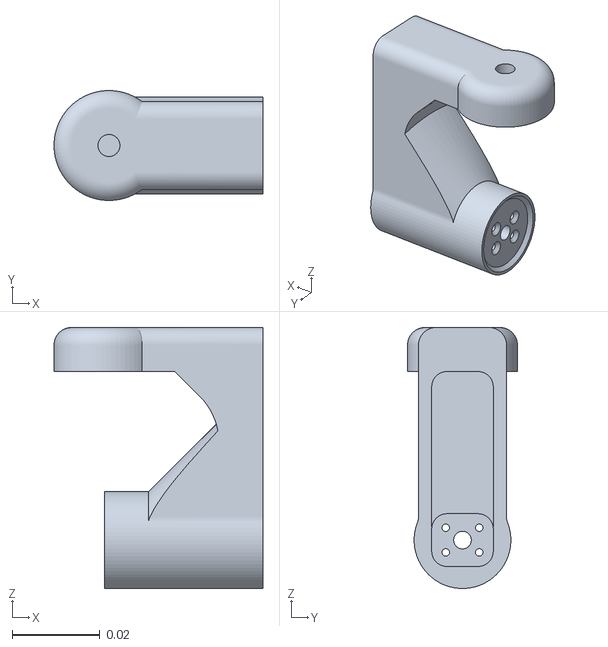
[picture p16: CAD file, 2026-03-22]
perseverance/urdf/frontsteeringarm.stl
0.0475 x 0.025 x 0.0593

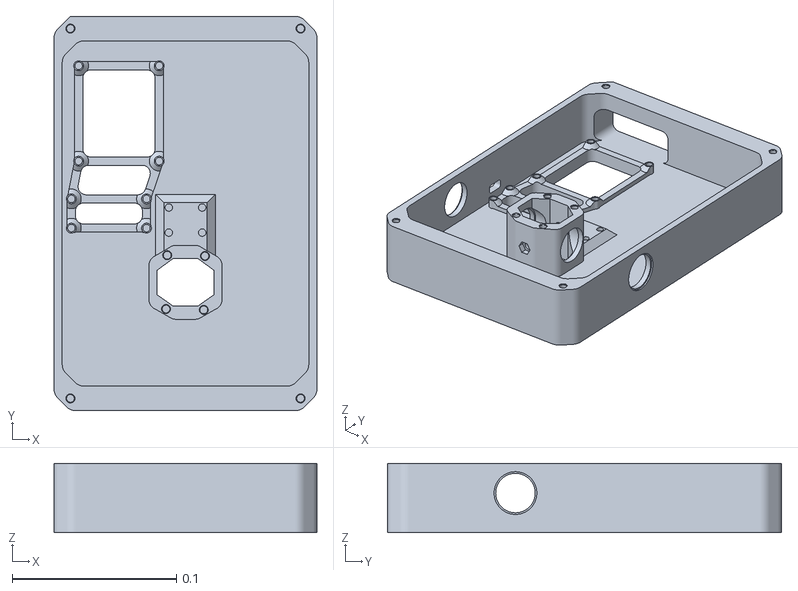
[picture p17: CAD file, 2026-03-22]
perseverance/urdf/base_link.stl
0.16 x 0.24 x 0.042

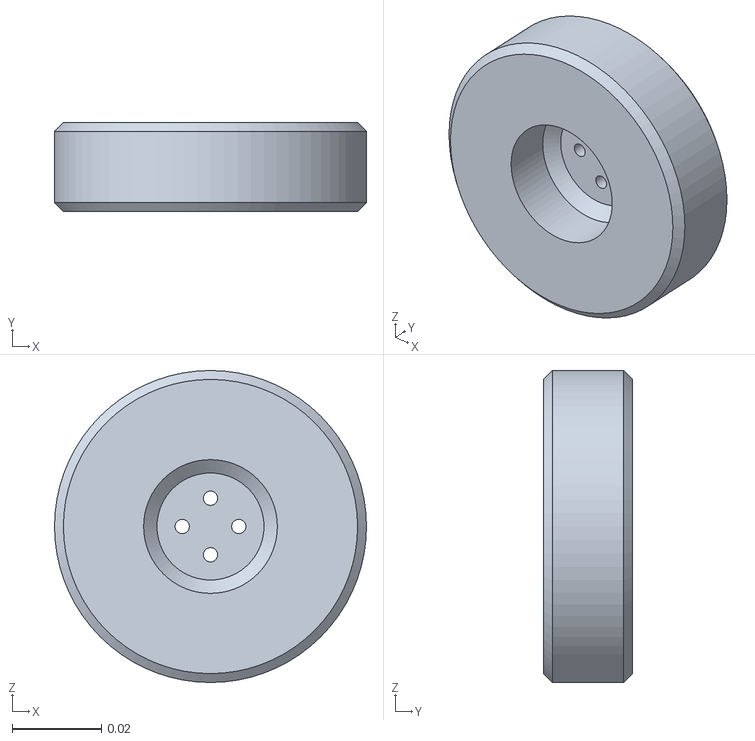
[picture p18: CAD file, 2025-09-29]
perseverance/urdf/wheel.stl
0.07 x 0.02 x 0.07

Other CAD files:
perseverance/urdf/rightrocker.stl

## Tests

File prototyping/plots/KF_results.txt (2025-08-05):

===========================================================================
KALMAN FILTER PERFORMANCE COMPARISON
===========================================================================
State           Dynamic RMSE    Kinematic RMSE  Mecanum RMSE    Best Model
---------------------------------------------------------------------------
x [mm]          28.050          1.892           1.800           Mecanum
y [mm]          25.124          2.715           1.608           Mecanum
theta [rad]     0.098           0.067           0.075           Kinematic
vx [mm/s]       65.037          13.935          20.095          Kinematic
vy [mm/s]       47.156          10.845          12.080          Kinematic
omega [rad/s]   0.304           0.035           0.046           Kinematic
---------------------------------------------------------------------------
Overall         27.628          4.915           5.951           Kinematic

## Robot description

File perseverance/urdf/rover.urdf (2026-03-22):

<?xml version="1.0" ?>
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
<robot name="perseverance">
  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
  <link name="base_link_centered"/>

  <joint name="base_link_centered_to_base_link" type="fixed">
    <parent link="base_link_centered"/>
    <child link="base_link"/>
    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
    <origin xyz="-0.015030 0.025000 0.000000" rpy="0.000000 0.000000 1.570796"/>
  </joint>

  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
  <link name="base_link">
    <inertial>
      <origin xyz="-0.0234123 -0.0139367 0.0131799" rpy="0 0 0"/>
      <mass value="1.18472"/>
      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
    </inertial>
    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
  </link>
  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
  <link name="rearsteeringarm">
    <inertial>
      <origin xyz="0.0165409 4.47932e-09 -0.0224062" rpy="0 0 0"/>
      <mass value="0.0308339"/>
      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
    </inertial>
    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
  </link>
  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
  <link name="wheel">
    <inertial>
      <origin xyz="-3.19706e-19 3.11993e-18 0.00460287" rpy="0 0 0"/>
      <mass value="0.0820664"/>
      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
    </inertial>
    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
  </link>
  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
  <joint name="bl_wheel" type="continuous">
    <origin xyz="-0.005 2.77556e-17 -0.0463814" rpy="-1.5708 1.249e-16 -1.5708"/>
    <parent link="rearsteeringarm"/>
    <child link="wheel"/>
    <axis xyz="0 0 1"/>
    <limit effort="10" velocity="10"/>
  </joint>
  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
  <joint name="bl_steering" type="revolute">
    <origin xyz="0.1025 0.10997 -0.00127218" rpy="-1.249e-16 4.18641e-16 3.141593"/>
    <parent link="base_link"/>
    <child link="rearsteeringarm"/>
    <axis xyz="0 0 1"/>
    <limit effort="10" velocity="10" lower="-0.610865" upper="0.610865"/>
  </joint>
  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
  <link name="rearsteeringarm_2">
    <inertial>
      <origin xyz="0.0165409 4.47932e-09 -0.0224062" rpy="0 0 0"/>
      <mass value="0.0308339"/>
      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
    </inertial>
    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
  </link>
  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
  <link name="wheel_2">
    <inertial>
      <origin xyz="2.74893e-17 3.11993e-18 0.00460287" rpy="0 0 0"/>
      <mass value="0.0820664"/>
      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
    </inertial>
    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
  </link>
  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
  <joint name="br_wheel" type="continuous">
    <origin xyz="-0.005 5.55112e-17 -0.0463814" rpy="1.5708 -0 1.5708"/>
    <parent link="rearsteeringarm_2"/>
    <child link="wheel_2"/>
    <axis xyz="0 0 1"/>
    <limit effort="10" velocity="10"/>
  </joint>
  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
  <joint name="br_steering" type="revolute">
    <origin xyz="-0.1525 0.10997 -0.00127218" rpy="4.22436e-59 -1.37735e-59 0.000000"/>
    <parent link="base_link"/>
    <child link="rearsteeringarm_2"/>
    <axis xyz="0 0 1"/>
    <limit effort="10" velocity="10" lower="-0.610865" upper="0.610865"/>
  </joint>
  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
  <link name="frontsteeringarm">
    <inertial>
      <origin xyz="0.0163817 3.64678e-09 -0.0208537" rpy="0 0 0"/>
      <mass value="0.0304253"/>
      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
    </inertial>
    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
  </link>
  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
  <link name="wheel_3">
    <inertial>
      <origin xyz="-1.47648e-19 3.11993e-18 0.00460287" rpy="0 0 0"/>
      <mass value="0.0820664"/>
      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
    </inertial>
    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
  </link>
  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
  <joint name="fl_wheel" type="continuous">
    <origin xyz="-0.005 2.77556e-17 -0.0433189" rpy="-1.5708 -0 -1.5708"/>
    <parent link="frontsteeringarm"/>
    <child link="wheel_3"/>
    <axis xyz="0 0 1"/>
    <limit effort="10" velocity="10"/>
  </joint>
  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
  <joint name="fl_steering" type="revolute">
    <origin xyz="0.1025 -0.140031 -0.0015" rpy="0 -0 3.14159"/>
    <parent link="base_link"/>
    <child link="frontsteeringarm"/>
    <axis xyz="0 0 1"/>
    <limit effort="10" velocity="10" lower="-0.610865" upper="0.610865"/>
  </joint>
  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
  <link name="frontsteeringarm_2">
    <inertial>
      <origin xyz="-0.0163817 -3.64678e-09 -0.0208537" rpy="0 0 0"/>
      <mass value="0.0304253"/>
      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
    </inertial>
    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
  </link>
  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
  <link name="wheel_4">
    <inertial>
      <origin xyz="-1.47648e-19 3.11993e-18 0.00460287" rpy="0 0 0"/>
      <mass value="0.0820664"/>
      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
    </inertial>
    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
  </link>
  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
  <joint name="fr_wheel" type="continuous">
    <origin xyz="0.005 2.77556e-17 -0.0433189" rpy="1.5708 3.93984e-31 -1.5708"/>
    <parent link="frontsteeringarm_2"/>
    <child link="wheel_4"/>
    <axis xyz="0 0 1"/>
    <limit effort="10" velocity="10"/>
  </joint>
  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
  <joint name="fr_steering" type="revolute">
    <origin xyz="-0.1525 -0.140031 -0.0015" rpy="0 -0 -3.14159"/>
    <parent link="base_link"/>
    <child link="frontsteeringarm_2"/>
    <axis xyz="0 0 1"/>
    <limit effort="10" velocity="10" lower="-0.610865" upper="0.610865"/>
  </joint>
  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
  <link name="wheel_5">
    <inertial>
      <origin xyz="-1.47648e-19 3.11993e-18 0.00460287" rpy="0 0 0"/>
      <mass value="0.0820664"/>
      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
    </inertial>
    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
  </link>
  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
  <joint name="mr_wheel" type="continuous">
    <origin xyz="-0.177 -0.00814152 -0.0476535" rpy="1.5708 -0 1.5708"/>
    <parent link="base_link"/>
    <child link="wheel_5"/>
    <axis xyz="0 0 1"/>
    <limit effort="10" velocity="10"/>
  </joint>
  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
  <link name="wheel_6">
    <inertial>
      <origin xyz="1.05344e-19 3.11993e-18 -0.000397125" rpy="0 0 0"/>
      <mass value="0.0820664"/>
      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
    </inertial>
    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
  </link>
  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
  <joint name="ml_wheel" type="continuous">
    <origin xyz="0.122 -0.00814152 -0.0476535" rpy="1.5708 -0 -1.5708"/>
    <parent link="base_link"/>
    <child link="wheel_6"/>
    <axis xyz="0 0 1"/>
    <limit effort="10" velocity="10"/>
  </joint>
</robot>

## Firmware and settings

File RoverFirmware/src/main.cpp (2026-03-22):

/**
 * @file main.cpp
 * @author Sharwin Patil (sharwinpatil@u.northwestern.edu)
 * @brief Rover's motor firmware using an Adafruit Feather M4 Express
 * @date 2024-09-016
 * @version 2.0
 *
 * This board needs to interact with the following hardware:
 * 1. 2 MotorShield Featherwings to control 6 DC motors (3 per shield) over I2C
 * 3. Read from 6 encoders (12 GPIO pins)
 * 4. Communicate with Raspberry Pi 5 over SPI
 *
 * RPI5 -> MCU (SPI):
 * - 6 motor speeds
 * - 4 servo positions (steering angles)
 * MCU -> RPI5 (SPI):
 * - 6 encoder positions (for wheel odometry)
 *
 * 1. Encoder Task: Reading Encoders and saving encoder count (1kHz)
 * 2. Motor Task: PID Control loop for drive motors and updating PWM signals (100Hz)
 * 3. Communication Task: Handle SPI communication with RPI5 (100Hz)
 * 4. Steering Task: Control steering servos based on RPI5 commands (100Hz)
 * 5. Heartbeat Task: Blink LED to indicate system is alive (0.25Hz)
 */


#include <Arduino.h>
#include <SPI.h>
#include <Servo.h>
#include <PID_v1.h>
#include <Encoder.h>
#include <Thread.h>
#include <Adafruit_MotorShield.h>
#include <Adafruit_SPIDevice.h>

#include "rover_pins.h"

#define SERIAL_BAUD 115200 // Baud rate for Serial communication
#define PWM_FREQ 20000 // 20 kHz PWM frequency for motor control

 // --- Task Frequencies ---
#define MOTOR_TASK_FREQ 100 // Frequency for task that runs PID position control for motors [Hz]
#define MOTOR_TASK_PERIOD_MS (1000 / MOTOR_TASK_FREQ)
#define ENCODER_TASK_FREQ 1000 // Frequency for task that reads motor encoders to report motor position [Hz]
#define ENCODER_TASK_PERIOD_MS (1000 / ENCODER_TASK_FREQ)
#define COMM_TASK_FREQ 100 // Frequency to handle communications between RPI5 and MCU[Hz]
#define COMM_TASK_PERIOD_MS (1000 / COMM_TASK_FREQ)
#define STEER_TASK_FREQ 100 // Frequency for task that handles steering servos [Hz]
#define STEER_TASK_PERIOD_MS (1000 / STEER_TASK_FREQ)
#define HEARTBEAT_TASK_FREQ 0.25 // Frequency for task that blinks LED to indicate system is alive[Hz]
#define HEARTBEAT_TASK_PERIOD_MS (1000 / HEARTBEAT_TASK_FREQ)

// Motor Shield with I2C addresses 0x60 and 0x61 hosting the left and right 3 drive motors respectively
Adafruit_MotorShield AFMSLeft = Adafruit_MotorShield(0x60);
Adafruit_MotorShield AFMSRight = Adafruit_MotorShield(0x61);

// Create motor objects
Adafruit_DCMotor* FLMotor = AFMSLeft.getMotor(1);
Adafruit_DCMotor* MLMotor = AFMSLeft.getMotor(2);
Adafruit_DCMotor* RLMotor = AFMSLeft.getMotor(3);
Adafruit_DCMotor* FRMotor = AFMSRight.getMotor(1);
Adafruit_DCMotor* MRMotor = AFMSRight.getMotor(2);
Adafruit_DCMotor* RRMotor = AFMSRight.getMotor(3);

// Array of pointers to each motor that aligns with command and encoder arrays
Adafruit_DCMotor* motors[6] = {FLMotor, FRMotor, MLMotor, MRMotor, RLMotor, RRMotor};

// Threads
Thread motorThread = Thread();
Thread encoderThread = Thread();
Thread steeringThread = Thread();
Thread commsThread = Thread();
Thread heartbeatThread = Thread();
Thread batteryMonitorThread = Thread();

// --- Shared Data and Mutexes ---
// Use volatile for variables shared between threads
volatile float motorSpeedCommands[6] = {0, 0, 0, 0, 0, 0}; // {FL, FR, ML, MR, RL, RR} [rad/s]
volatile float servoAngleCommands[4] = {0, 0, 0, 0}; // {FL, FR, RL, RR} [radians]
volatile long encoderCounts[6] = {0, 0, 0, 0, 0, 0}; // {FL, FR, ML, MR, RL, RR} [ticks]

// Global timing variables for tasks
uint32_t prevMotorUpdateUs = 0;
long prevEncoderCounts[6] = {0, 0, 0, 0, 0, 0};

// SPI Device for communication with RPI5
Adafruit_SPIDevice spiDevice(SPI_CS_PIN, SPI_SCK_PIN, SPI_MISO_PIN, SPI_MOSI_PIN);

// --- Peripherals and Controllers ---
// PID control instances
const double Kp = 2.0, Ki = 5.0, Kd = 1.0;
double pid_inputs[6], pid_outputs[6], pid_targets[6];

PID pid_controllers[6] = {
    PID(&pid_inputs[0], &pid_outputs[0], &pid_targets[0], Kp, Ki, Kd, DIRECT),
    PID(&pid_inputs[1], &pid_outputs[1], &pid_targets[1], Kp, Ki, Kd, DIRECT),
    PID(&pid_inputs[2], &pid_outputs[2], &pid_targets[2], Kp, Ki, Kd, DIRECT),
    PID(&pid_inputs[3], &pid_outputs[3], &pid_targets[3], Kp, Ki, Kd, DIRECT),
    PID(&pid_inputs[4], &pid_outputs[4], &pid_targets[4], Kp, Ki, Kd, DIRECT),
    PID(&pid_inputs[5], &pid_outputs[5], &pid_targets[5], Kp, Ki, Kd, DIRECT),
};

// Encoder instances
Encoder encoders[6] = {
    Encoder(FL_ENCODER_A_PIN, FL_ENCODER_B_PIN),
    Encoder(FR_ENCODER_A_PIN, FR_ENCODER_B_PIN),
    Encoder(ML_ENCODER_A_PIN, ML_ENCODER_B_PIN),
    Encoder(MR_ENCODER_A_PIN, MR_ENCODER_B_PIN),
    Encoder(RL_ENCODER_A_PIN, RL_ENCODER_B_PIN),
    Encoder(RR_ENCODER_A_PIN, RR_ENCODER_B_PIN),
};

// Servo instances
Servo servos[4];
const uint8_t servo_pins[4] = {
    FL_STEERING_SERVO_PIN,
    FR_STEERING_SERVO_PIN,
    RL_STEERING_SERVO_PIN,
    RR_STEERING_SERVO_PIN,
};

// ---------- Task Functions ----------

/**
 * @brief Encoder task running at 1kHz
 *
 * @note Stores latest encoder values from hardware encoders (ISR driven)
 * into shared encoderCounts array which will be communicated to RPI5
 * and used for PID feedback
 *
 */
void encoderTask() {
  for (uint8_t i = 0; i < 6; ++i) {
    encoderCounts[i] = encoders[i].read();
  }
}

/**
 * @brief Motor control task running at 200Hz
 *
 * @note Implements a PID control loop for each drive motor
 * using the encoder feedback to calculate motor velocities
 *
 */
void motorTask() {
  // Use microsecond timer for better dt precision
  uint32_t nowUs = micros();
  uint32_t dt_us = nowUs - prevMotorUpdateUs; // handles wrap-around for uint32_t
  prevMotorUpdateUs = nowUs;
  // Convert to seconds
  double dt = dt_us * 1e-6;

  // Save a local copy of the motor speed commands to minimize time spent
  // accessing the shared volatile array
  double local_motor_cmd[6];
  for (uint8_t i = 0; i < 6; ++i) {
    local_motor_cmd[i] = motorSpeedCommands[i];
  }

  for (uint8_t i = 0; i < 6; ++i) {
    long c = encoderCounts[i];
    double vel = (double)(c - prevEncoderCounts[i]) / dt; // ticks/s
    prevEncoderCounts[i] = c;
    pid_inputs[i] = vel;
    pid_targets[i] = local_motor_cmd[i];
    pid_controllers[i].Compute();
    double output = pid_outputs[i];
    uint16_t pwm = static_cast<uint16_t>(fabs(output));
    motors[i]->setSpeedFine(pwm);
    motors[i]->run((output >= 0) ? FORWARD : BACKWARD);
  }
}


/**
 * @brief Steering task running at 100Hz
 *
 * @note Accesses shared servoAngleCommands array to set servo positions
 *
 */
void steeringTask() {
  for (uint8_t i = 0; i < 4; i++) {
    // Convert radians to degrees for Servo library
    float degrees = degrees(servoAngleCommands[i]);
    servos[i].write(map(degrees, -90, 90, 0, 180));
  }
}

/**
 * @brief Communication task running at 100Hz
 *
 * @note Handles SPI communication with RPI5 and accesses shared command arrays
 *
 */
void commsTask() {
  // Prepare transmission buffer with encoder counts (6 x 4 bytes = 24 bytes)
  uint8_t txBuffer[24];
  uint8_t rxBuffer[40]; // Receive buffer for motor commands (6x4) + servo commands (4x4) = 40 bytes

  // Pack encoder counts into transmission buffer as little-endian 32-bit values
  for (uint8_t i = 0; i < 6; ++i) {
    uint32_t count = (uint32_t)encoderCounts[i];
    txBuffer[i * 4 + 0] = (count >> 0) & 0xFF;
    txBuffer[i * 4 + 1] = (count >> 8) & 0xFF;
    txBuffer[i * 4 + 2] = (count >> 16) & 0xFF;
    txBuffer[i * 4 + 3] = (count >> 24) & 0xFF;
  }

  // Perform SPI transaction: send encoder data and receive commands
  if (spiDevice.write_then_read(txBuffer, sizeof(txBuffer), rxBuffer, sizeof(rxBuffer))) {

    // Unpack received motor speed commands (6 floats)
    for (int i = 0; i < 6; ++i) {
      union { uint32_t u; float f; } u32f;
      u32f.u = ((uint32_t)rxBuffer[i * 4 + 0] << 0) |
        ((uint32_t)rxBuffer[i * 4 + 1] << 8) |
        ((uint32_t)rxBuffer[i * 4 + 2] << 16) |
        ((uint32_t)rxBuffer[i * 4 + 3] << 24);
      motorSpeedCommands[i] = u32f.f;
    }

    // Unpack received servo angle commands (4 floats)
    for (int i = 0; i < 4; ++i) {
      union { uint32_t u; float f; } u32f;
      uint8_t* ptr = &rxBuffer[24 + i * 4]; // Start after motor commands (6*4=24 bytes)
      u32f.u = ((uint32_t)ptr[0] << 0) |
        ((uint32_t)ptr[1] << 8) |
        ((uint32_t)ptr[2] << 16) |
        ((uint32_t)ptr[3] << 24);
      servoAngleCommands[i] = u32f.f;
    }
  }
  // If SPI transaction fails, commands remain at their previous values
}

/**
 * @brief Heartbeat task running at 1Hz
 *
 * @note Indicates system is running
 *
 */
void heartbeatTask() {
  digitalWrite(LED_BUILTIN, HIGH);
  delay(100);
  digitalWrite(LED_BUILTIN, LOW);
  delay(900);
}

void setup() {
  // Initialize Serial port
  Serial.begin(SERIAL_BAUD);

  // Initialize output pins
  pinMode(LED_BUILTIN, OUTPUT);
  pinMode(BATTERY_CHARGE_ENABLE_PIN, OUTPUT);

  // Attach servo motors
  for (uint8_t i = 0; i < 4; i++) {
    pinMode(servo_pins[i], OUTPUT);
    servos[i].attach(servo_pins[i]);
  }

  // Set up PID controllers
  for (uint8_t i = 0; i < 6; ++i) {
    pid_controllers[i].SetMode(AUTOMATIC);
    pid_controllers[i].SetOutputLimits(-4095, 4085); // Use 12-bit PWM
    pid_controllers[i].SetSampleTime(MOTOR_TASK_PERIOD_MS); // = 5 ms for 200 Hz
  }

  // Initialize Motor Shields
  AFMSLeft.begin();
  AFMSRight.begin();

  // Enable motors
  for (uint8_t i = 0; i < 6; i++) {
    motors[i]->setSpeed(0);
    motors[i]->run(RELEASE);
  }

  // Initialize SPI
  spiDevice.begin();

  // Initialize timing baseline for motor task
  prevMotorUpdateUs = micros();

  // Attach callbacks and set intervals for each thread
  motorThread.onRun(motorTask);
  encoderThread.onRun(encoderTask);
  steeringThread.onRun(steeringTask);
  commsThread.onRun(commsTask);
  heartbeatThread.onRun(heartbeatTask);
  motorThread.setInterval(MOTOR_TASK_PERIOD_MS);
  encoderThread.setInterval(ENCODER_TASK_PERIOD_MS);
  steeringThread.setInterval(STEER_TASK_PERIOD_MS);
  commsThread.setInterval(COMM_TASK_PERIOD_MS);
  heartbeatThread.setInterval(HEARTBEAT_TASK_PERIOD_MS);
}

void loop() {
  // Check each thread in order of priority
  if (encoderThread.shouldRun()) { encoderThread.run(); }
  if (motorThread.shouldRun()) { motorThread.run(); }
  if (steeringThread.shouldRun()) { steeringThread.run(); }
  if (commsThread.shouldRun()) { commsThread.run(); }
  if (heartbeatThread.shouldRun()) { heartbeatThread.run(); }
}

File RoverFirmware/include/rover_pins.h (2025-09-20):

#ifndef ROVER_PINS_H
#define ROVER_PINS_H

// Pin Map for Rover Control
// Rationale:
//  - Keep default SPI (MOSI=11, MISO=12, SCK=13) free; only CS defined explicitly
//  - Reserve pin 13 for onboard LED only
//  - Use primary I2C bus SDA=18, SCL=19
//  - Group each wheel's encoder pins adjacently where possible

// Front Left (FL)
#define FL_ENCODER_A_PIN 5
#define FL_ENCODER_B_PIN 6
#define FL_STEERING_SERVO_PIN 7

// Front Right (FR)
#define FR_ENCODER_A_PIN 14
#define FR_ENCODER_B_PIN 15
#define FR_STEERING_SERVO_PIN 8

// Middle Left (ML)
#define ML_ENCODER_A_PIN 23
#define ML_ENCODER_B_PIN 24

// Middle Right (MR)
#define MR_ENCODER_A_PIN 27
#define MR_ENCODER_B_PIN 28

// Rear Left (RL)
#define RL_ENCODER_A_PIN 31
#define RL_ENCODER_B_PIN 32
#define RL_STEERING_SERVO_PIN 33

// Rear Right (RR)
#define RR_ENCODER_A_PIN 35
#define RR_ENCODER_B_PIN 36
#define RR_STEERING_SERVO_PIN 37

// SPI Pins
#define SPI_CS_PIN 10
#define SPI_MOSI_PIN 11
#define SPI_MISO_PIN 12
#define SPI_SCK_PIN 13

// RPI5 Pins
// MOSI = GPIO10(phys 19)
// MISO = GPIO9(phys 21)
// SCLK = GPIO11(phys 23)
// CE0 = GPIO8(phys 24)

// GPIO pin to signal low battery condition and enable charging circuit to operate
#define BATTERY_CHARGE_ENABLE_PIN 38

// Sanity compile-time checks (optional - enable if desired)
// static_assert(DEBUG_LED != FR_STEERING_SERVO_PIN, "LED and FR servo share a pin");

#endif // !ROVER_PINS_H

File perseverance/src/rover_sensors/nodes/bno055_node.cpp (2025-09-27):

#include "rover_sensors/nodes/bno055_node.hpp"
#include "rover_sensors/drivers/bno055.hpp"

#include "rclcpp/rclcpp.hpp"
#include "sensor_msgs/msg/imu.hpp"
#include "sensor_msgs/msg/magnetic_field.hpp"
#include "sensor_msgs/msg/temperature.hpp"

#define I2C_DEVICE "/dev/i2c-1"

constexpr const char* IMU_TOPIC = "sensors/raw/imu";
constexpr const char* MAG_TOPIC = "sensors/raw/mag";
constexpr const char* TEMP_TOPIC = "sensors/raw/temp";
constexpr const char* IMU_FILTERED_TOPIC = "sensors/filtered/imu";
constexpr const char* MAG_FILTERED_TOPIC = "sensors/filtered/mag";
constexpr const char* TEMP_FILTERED_TOPIC = "sensors/filtered/temp";

BNO055Node::BNO055Node() : Node("BNO055_Sensor") {
  // Declare parameters
  std::string sensor_frame_id = this->declare_parameter("sensor_frame_id", "imu_link");
  double sensorPollFreq = this->declare_parameter("sensor_poll_freq", 100.0); // [Hz]
  double temp_filter_alpha = this->declare_parameter("temp_filter_alpha", 0.8);
  double temp_filter_beta = this->declare_parameter("temp_filter_beta", 0.01);
  double imu_filter_lin_accel_alpha = this->declare_parameter("imu_filter_lin_accel_alpha", 0.8);
  double imu_filter_lin_accel_beta = this->declare_parameter("imu_filter_lin_accel_beta", 0.01);
  double imu_filter_ang_vel_alpha = this->declare_parameter("imu_filter_ang_vel_alpha", 0.8);
  double imu_filter_ang_vel_beta = this->declare_parameter("imu_filter_ang_vel_beta", 0.01);
  double imu_filter_orient_alpha = this->declare_parameter("imu_filter_orient_alpha", 0.8);
  double imu_filter_orient_beta = this->declare_parameter("imu_filter_orient_beta", 0.01);
  double mag_filter_alpha = this->declare_parameter("mag_filter_alpha", 0.8);
  double mag_filter_beta = this->declare_parameter("mag_filter_beta", 0.01);
  // Get parameter from yaml file
  sensor_frame_id = this->get_parameter("sensor_frame_id").as_string();
  sensorPollFreq = this->get_parameter("sensor_poll_freq").as_double();
  temp_filter_alpha = this->get_parameter("temp_filter_alpha").as_double();
  temp_filter_beta = this->get_parameter("temp_filter_beta").as_double();
  imu_filter_lin_accel_alpha = this->get_parameter("imu_filter_lin_accel_alpha").as_double();
  imu_filter_lin_accel_beta = this->get_parameter("imu_filter_lin_accel_beta").as_double();
  imu_filter_ang_vel_alpha = this->get_parameter("imu_filter_ang_vel_alpha").as_double();
  imu_filter_ang_vel_beta = this->get_parameter("imu_filter_ang_vel_beta").as_double();
  imu_filter_orient_alpha = this->get_parameter("imu_filter_orient_alpha").as_double();
  imu_filter_orient_beta = this->get_parameter("imu_filter_orient_beta").as_double();
  mag_filter_alpha = this->get_parameter("mag_filter_alpha").as_double();
  mag_filter_beta = this->get_parameter("mag_filter_beta").as_double();

  // Initialize the AlphaBeta Filters
  this->tempFilter = TempABFilter(temp_filter_alpha, temp_filter_beta);
  this->imuFilter = IMUABFilter(imu_filter_lin_accel_alpha, imu_filter_lin_accel_beta,
    imu_filter_ang_vel_alpha, imu_filter_ang_vel_beta,
    imu_filter_orient_alpha, imu_filter_orient_beta);
  this->magFilter = MagABFilter(mag_filter_alpha, mag_filter_beta);

  // Initialize the BNO055 sensor
  try {
    this->sensor.init(I2C_DEVICE, BNO055_ADDRESS_A);
  }
  catch (const std::exception& e) {
    rclcpp::shutdown();
    throw std::runtime_error("BNO055 Sensor offline, shutting down node: " + std::string(e.what()));
  }

  RCLCPP_INFO(this->get_logger(), "BNO055 Sensor online!");

  // Initialize the publishers
  const auto qos = rclcpp::QoS(rclcpp::KeepLast(10)).reliable().durability_volatile();
  this->imu_pub = this->create_publisher<sensor_msgs::msg::Imu>(IMU_TOPIC, qos);
  this->mag_pub = this->create_publisher<sensor_msgs::msg::MagneticField>(MAG_TOPIC, qos);
  this->temp_pub = this->create_publisher<sensor_msgs::msg::Temperature>(TEMP_TOPIC, qos);
  this->imu_filtered_pub = this->create_publisher<sensor_msgs::msg::Imu>(IMU_FILTERED_TOPIC, qos);
  this->mag_filtered_pub = this->create_publisher<sensor_msgs::msg::MagneticField>(MAG_FILTERED_TOPIC, qos);
  this->temp_filtered_pub = this->create_publisher<sensor_msgs::msg::Temperature>(TEMP_FILTERED_TOPIC, qos);

  RCLCPP_INFO(this->get_logger(),
    "BNO055 Sensor publishing on topics: Raw: (%s), (%s), (%s) Filtered: (%s), (%s), (%s) at %.1f Hz",
    IMU_TOPIC, MAG_TOPIC, TEMP_TOPIC, IMU_FILTERED_TOPIC, MAG_FILTERED_TOPIC, TEMP_FILTERED_TOPIC, sensorPollFreq
  );

  // Create a timer to read the sensor and publish the data
  this->timer = this->create_wall_timer(
    std::chrono::duration<double>(1.0 / sensorPollFreq),
    [this, sensor_frame_id]() -> void {
    IMURecord record = this->sensor.read();

    // IMU data
    sensor_msgs::msg::Imu imu_msg;
    imu_msg.header.stamp = this->now();
    imu_msg.header.frame_id = sensor_frame_id;
    imu_msg.linear_acceleration.x = record.raw_linear_acceleration_x;
    imu_msg.linear_acceleration.y = record.raw_linear_acceleration_y;
    imu_msg.linear_acceleration.z = record.raw_linear_acceleration_z;
    imu_msg.angular_velocity.x = record.raw_angular_velocity_x;
    imu_msg.angular_velocity.y = record.raw_angular_velocity_y;
    imu_msg.angular_velocity.z = record.raw_angular_velocity_z;
    imu_msg.orientation.w = record.fused_orientation_w;
    imu_msg.orientation.x = record.fused_orientation_x;
    imu_msg.orientation.y = record.fused_orientation_y;
    imu_msg.orientation.z = record.fused_orientation_z;

    // Magnetic field data
    sensor_msgs::msg::MagneticField mag_msg;
    mag_msg.header.stamp = this->now();
    mag_msg.header.frame_id = sensor_frame_id;
    mag_msg.magnetic_field.x = record.raw_magnetic_field_x;
    mag_msg.magnetic_field.y = record.raw_magnetic_field_y;
    mag_msg.magnetic_field.z = record.raw_magnetic_field_z;

    // Temperature data
    sensor_msgs::msg::Temperature temp_msg;
    temp_msg.header.stamp = this->now();
    temp_msg.header.frame_id = sensor_frame_id;
    temp_msg.temperature = record.temperature;

    // Publish the data
    this->imu_pub->publish(imu_msg);
    this->mag_pub->publish(mag_msg);
    this->temp_pub->publish(temp_msg);

    // Filter the data and publish it as well
    const auto filteredTempMsg = this->tempFilter.update(temp_msg);
    const auto filteredImuMsg = this->imuFilter.update(imu_msg);
    const auto filteredMagMsg = this->magFilter.update(mag_msg);
    this->temp_filtered_pub->publish(filteredTempMsg);
    this->imu_filtered_pub->publish(filteredImuMsg);
    this->mag_filtered_pub->publish(filteredMagMsg);
  });
}

int main(int argc, char* argv[]) {
  rclcpp::init(argc, argv);
  try {
    auto node = std::make_shared<BNO055Node>();
    rclcpp::spin(node);
  }
  catch (const std::exception& e) {
    RCLCPP_FATAL(rclcpp::get_logger("rclcpp"), e.what());
  }
  rclcpp::shutdown();
  return 0;
}

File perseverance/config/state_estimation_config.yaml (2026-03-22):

state_estimator:
  ros__parameters:
    timer_frequency: 1.0 # [Hz]
    initial_x: 0.0 # Initial x position [m]
    initial_y: 0.0 # Initial y position [m]
    initial_theta: 0.0 # Initial orientation [rad]
    wheel_radius: 0.035 # Wheel radius [m]
    front_wheel_base: 0.131889 # Middle Wheel to Front Wheel distance along the Robot X-axis [m]
    rear_wheel_base: 0.118112 # Middle Wheel to Rear Wheel distance along the Robot X-axis [m]
    base_to_wheel_height: 0.044850 # Height of the steering pivot above the wheel axle [m]
    max_steering_front: 0.610865 # Front wheel max steering angle [rad] (35.0 deg)
    max_steering_rear: 0.610865 # Rear wheel max steering angle [rad] (35.0 deg)

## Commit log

2025-07-31 Dynamic to Kinematic comparison
2025-08-16 Mutex for getting latest IMU message
2025-08-18 Using const returns and array instead of maps for wheel velocities
2025-08-19 Created sensors package with IMU
2025-08-19 Added other filter values
2025-08-19 Fixed state update and simulated IMU data
    [simulated_imu.hpp]
2025-08-19 Conditionally launch simulated IMU
2025-08-21 LaserManager and sensors restructuring
2025-08-21 Simulated LiDaR
2025-08-21 Static transforms for sim sensors
2025-08-24 Started an Auto-BOM
2025-08-26 CAD images
2025-08-27 Updated constants after measuring CAD robot
2025-08-27 Updating constants with correct naming
    [state_estimation_config.yaml]
2025-08-27 Bigger wheel
2025-08-28 Updating kalman filter
2025-09-01 TODO updates and date for driver
2025-09-01 Pass in frame into lambda
2025-09-01 Using duration instead of milliseconds
2025-09-01 Created RoverMotorControl Teensy Project
2025-09-01 Changed board to Teensy 4.1 and outlined commands
2025-09-01 Created wheel data
2025-09-06 Switched to arduino framework
2025-09-06 Use SPI Polling
2025-09-14 Update README with Adafruit motor driver information
2025-09-19 Rewrote RMC with AdafruitMotors, SPI, and ArduinoThreads
2025-09-19 Editing board to M4 Express
2025-09-19 millis() -> micros()
2025-09-27 Restructuring ROS packages (#2)
    [CPPLINT.cfg]
2025-09-28 Added wheel vectors
2025-09-28 Steering examples
2025-09-28 New steering planner for ackermann
2025-09-28 Draw simulated travel arcs for each wheel
2025-09-28 Note about steering planner
2025-09-29 Adding test URDF
    [3mm_m3.stl, bevel_0_85m_18t_45deg.stl, bevel_0_85m_18t_45deg__2.stl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]
2025-10-31 Imported URDF from onshape
    [leftbogie.stl, leftrocker.stl, mg995.stl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]
2025-11-01 Created node and started template SPI read/write
2025-11-01 Perseverance URDF (from OnShape) (#3)
    [base_link.stl, frontsteeringarm.stl, rearsteeringarm.stl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]
2025-12-20 Steering Planner and Trajectory Generator (#4)
2026-03-03 Updating firmware with board pinouts
2026-03-03 Deleted meshes folder and moved everything to URDF
    [3mm_m3.stl, base_link.stl, bevel_0_85m_18t_45deg.stl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]
2026-03-03 Updating files
    [base_link.stl, bevel_0_85m_18t_45deg.stl, leftrocker.stl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]
2026-03-03 Ran converter again
    [base_link.stl, bevel_0_85m_18t_45deg.stl, frontsteeringarm.stl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]
2026-03-07 Deleted extra stl files
    [base_link.stl, bevel_0_85m_18t_45deg.stl, frontsteeringarm.stl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]
2026-03-07 Fixed script
    [rover.urdf]
2026-03-22 Removed battery monitor
2026-03-22 Fixing generation tool and applying automated edits to urdf
    [3mm_m3.stl, base_link.stl, bevel_0_85m_18t_45deg__2.stl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]
2026-03-22 Updated URDF
    [rover.urdf]
2026-03-22 Updated steering limits and automatically update config file
    [rover.urdf]
2026-03-22 Sensor Adapters and subscribers for EKF
2026-03-23 Cleaned Sensor Adapters
2026-04-30 Throttle logging for state estimation
2026-06-22 Remove Battery Monitor Task from RoverFirmware README
    Task was deleted; removes the task table row, Adafruit_MAX1704X
    dependency entry, and the Battery Monitor Task detail section.
    Claude-Session: https://claude.ai/code/session_01RBHrcKKBRijMbagW6wpVv7
